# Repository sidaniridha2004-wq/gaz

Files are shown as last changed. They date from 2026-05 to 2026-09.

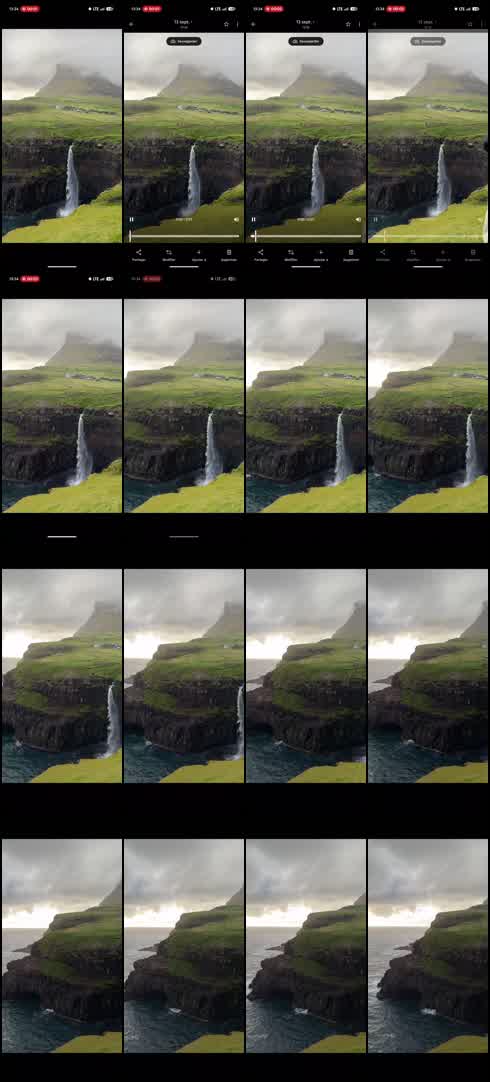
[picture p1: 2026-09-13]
video-analysis/contact-sheet.jpg

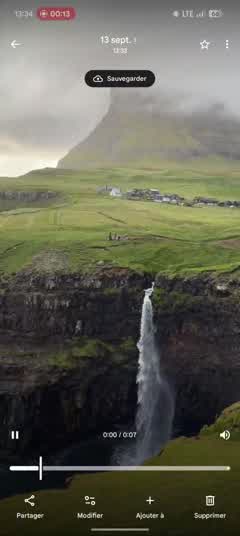
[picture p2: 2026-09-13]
video-analysis/frames/frame-5.jpg

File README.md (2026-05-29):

# Intelligent Home Gas & CO Detection Safety System

An ESP32-based safety system that detects carbon monoxide (CO) and combustible
gas (LPG / methane / propane) in every room of a house and **automatically shuts
off the gas supply at the source** when a confirmed leak is detected.

The system is split into two firmware subsystems that talk over **ESP-NOW**
(router-free, peer-to-peer Wi-Fi):

```
   ┌────────────────────┐        ESP-NOW (encrypted, <5 ms)        ┌───────────────────────────┐
   │  Sensor Node (xN)   │  ───────────────────────────────────▶   │   Central Control Unit     │
   │  per room           │     ALERT / STATUS / CLEAR packets       │   (Hub @ gas source)       │
   │                     │                                          │                            │
   │  ESP32              │                                          │  ESP32                     │
   │  MQ-7  (CO)         │                                          │  Relay ─ Servo ─ Ball valve│
   │  MQ-2  (LPG)        │                                          │  Buzzer                    │
   │  LiPo + TP4056      │                                          │  16x2 I2C LCD              │
   │                     │                                          │  SIM800L GSM (SMS)         │
   └────────────────────┘                                          │  Reset button (interlock)  │
                                                                    └───────────────────────────┘
```

## Repository layout

```
gas-safety-system/
├── platformio.ini              # two build envs: sensor_node + hub
├── lib/common/protocol.h       # shared ESP-NOW packet + thresholds + timing
├── src/
│   ├── sensor_node/
│   │   ├── main.cpp            # sampling, warm-up cal, vote, ESP-NOW TX
│   │   └── mq_sensor.{h,cpp}   # Rs/R0 -> ppm gas-sensor driver
│   └── hub/
│       ├── main.cpp            # ESP-NOW RX, valve, LCD, buzzer, GSM, FSM
│       └── node_registry.h     # MAC <-> room table (edit for your install)
└── docs/
    ├── BOM.md                  # bill of materials + cost
    ├── wiring.md               # pin-by-pin connections
    ├── calibration.md          # MQ sensor calibration procedure
    ├── actuator_3d_print.md    # 3D-printed valve clamp / coupler
    └── test_plan.md            # validation experiments
```

## How it works

### Sensor node (one per room)
1. **Warm-up (120 s):** the MQ heaters stabilise. During this window the node
   averages the clean-air sensor resistance to compute `R0`.
2. **Sampling (every 500 ms):** each sensor's voltage is read on an ADC1 pin,
   converted to a resistance `Rs`, and turned into ppm with the datasheet curve
   `ppm = A·(Rs/R0)^B`.
3. **Majority vote (2 of 3):** a reading only counts as a trip if at least 2 of
   the last 3 samples are over threshold — this rejects single-sample spikes.
4. **Alert:** on a confirmed trip (`CO ≥ 200 ppm` or `LPG ≥ 1000 ppm`) the node
   sends an encrypted `ALERT` packet to the hub (rate-limited to 1 per 10 s).
   It also sends a `STATUS` heartbeat every 5 s and a `CLEAR` packet once the
   air drops back below the lower hysteresis levels.

### Central hub (at the gas source)
On receiving an `ALERT` it executes the **fast safety path in under 1 second**:
close the valve → sound the buzzer → update the LCD. It then sends an SMS to the
homeowner (slower, done after the valve is already shut).

The valve is held **CLOSED** until **both** conditions are met (safety interlock):
* every room reports gas back to safe levels, **and**
* the physical **reset button** on the hub is pressed.

```
 NORMAL ──(alert)──▶ ALARM ──(all rooms clear)──▶ AWAIT_RESET ──(reset btn)──▶ NORMAL
   ▲                                                   │
   └──────────────── (gas returns) ◀───────────────────┘
```

## Build & flash (PlatformIO)

Each room is its own build environment (`node_living_room`, `node_kitchen`,
`node_bedroom`, …). Add a room by copying a `node_*` block in `platformio.ini`
and changing `ROOM_ID` / `ROOM_NAME`. Verified: all environments compile for
`esp32dev`.

```bash
# Install PlatformIO Core (once)
pip install platformio

# Build everything (sanity check)
pio run

# --- Hub ---
pio run -e hub -t upload
pio device monitor -b 115200          # note the printed HUB STA MAC

# --- Sensor nodes (one env per room) ---
pio run -e node_living_room -t upload
pio run -e node_kitchen     -t upload
pio run -e node_bedroom     -t upload
```

### One-time pairing procedure
1. Flash the **hub**, open the serial monitor, copy the printed
   `HUB STA MAC` into `HUB_MAC_BYTES` in `lib/common/protocol.h`.
2. Flash each **node**; copy each printed `Node STA MAC` + its room into
   `src/hub/node_registry.h` (the `roomId` there must match the env's `ROOM_ID`).
3. Re-flash the hub. Nodes and hub now trust each other (encrypted ESP-NOW).
4. Set the homeowner phone number in the `hub` env build flags, e.g.
   `-DHOMEOWNER_PHONE='"+15551234567"'`. Use `-DGSM_ENABLE=0` to build/test
   without a SIM800L attached.

## Key configuration (in `lib/common/protocol.h`)

| Setting | Default | Meaning |
|---|---|---|
| `CO_THRESHOLD_PPM` | 200 | CO alert trip point |
| `LPG_THRESHOLD_PPM` | 1000 | combustible-gas alert trip point |
| `SAMPLE_PERIOD_MS` | 500 | ADC sampling cadence |
| `WARMUP_SEC` | 120 | sensor warm-up / R0 calibration |
| `VOTE_NEEDED / VOTE_WINDOW` | 2 / 3 | majority vote |
| `MIN_ALERT_GAP_MS` | 10000 | min interval between alerts per node |
| `VALVE_OPEN_DEG / CLOSED_DEG` | 0 / 90 | servo angles |

Build-flag options: `ESPNOW_ENCRYPT` (1/0), `GSM_ENABLE` (1/0),
`BOOT_VALVE_OPEN` (1/0), `HOMEOWNER_PHONE`, `ROOM_ID`, `ROOM_NAME`.

## Important engineering notes & limitations

* **ADC1 only on nodes.** ESP-NOW uses the Wi-Fi radio, which makes ADC2 pins
  unusable. The sensors are therefore on GPIO34/35 (ADC1).
* **MQ-7 CO accuracy.** A laboratory-grade MQ-7 reading needs a dual-voltage
  heater cycle (5 V/1.4 V). This prototype runs the common constant-5 V module,
  which is adequate for threshold alarming but not metrology — see
  `docs/calibration.md`.
* **Encrypted-peer limit.** The ESP32 supports at most **6 encrypted** ESP-NOW
  peers. For more than 6 rooms either build with `-DESPNOW_ENCRYPT=0` or run
  multiple hub radios. (The "unlimited nodes" goal holds for the *unencrypted*
  configuration.)
* **Curve constants must be calibrated.** The `A`, `B` and clean-air ratios in
  `src/sensor_node/main.cpp` are datasheet starting points; calibrate against a
  reference per `docs/calibration.md` before trusting absolute ppm values.
* **Safety scope.** This is an academic prototype demonstrating the full
  electromechanical + firmware integration. It is **not** a certified life-safety
  appliance and should not be relied upon as a sole protection device.

See `docs/` for the bill of materials, wiring, calibration, 3D-printed actuator,
and the validation test plan.

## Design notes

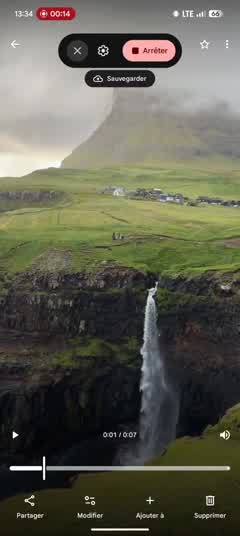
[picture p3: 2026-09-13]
video-analysis/frames/frame-6.jpg

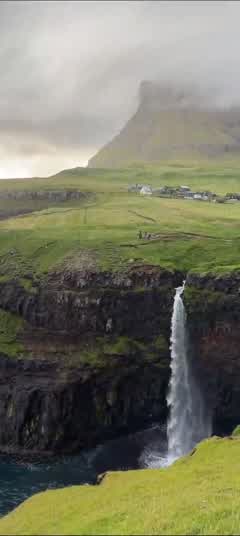
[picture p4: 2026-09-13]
video-analysis/frames/frame-4.jpg

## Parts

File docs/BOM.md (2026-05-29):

# Bill of Materials (BOM)

Indicative hobbyist prices (USD). A **3-room** system = 3 sensor nodes + 1 hub.

## Per sensor node (×N rooms)

| # | Component | Qty | ~Unit | Notes |
|---|---|----:|---:|---|
| 1 | ESP32 DevKit (WROOM-32) | 1 | $4.50 | dual-core, Wi-Fi/ESP-NOW |
| 2 | MQ-7 module (CO) | 1 | $2.00 | analog output |
| 3 | MQ-2 module (LPG/methane) | 1 | $1.80 | analog output |
| 4 | 3.7 V LiPo cell (1200–2000 mAh) | 1 | $4.00 | runtime depends on heaters |
| 5 | TP4056 charge module (w/ protection) | 1 | $0.60 | USB-C charging |
| 6 | MT3608 / 5 V boost converter | 1 | $0.70 | MQ heaters need 5 V |
| 7 | Resistors (divider 10k/20k ×2, batt 2×100k) | — | $0.20 | ADC scaling |
| 8 | Enclosure + vents + wiring | 1 | $2.00 | ventilated for airflow |
| | **Node subtotal** | | **≈ $15.6** | |

> The MQ heaters draw ~150 mA at 5 V continuously, so a node is effectively a
> low-power *plugged* device; the LiPo is primarily for outage ride-through.
> For a permanently battery-only node, budget a larger cell or USB power.

## Central hub (×1)

| # | Component | Qty | ~Unit | Notes |
|---|---|----:|---:|---|
| 1 | ESP32 DevKit (WROOM-32) | 1 | $4.50 | hub controller |
| 2 | MG996R servo (metal gear) | 1 | $3.50 | valve actuator |
| 3 | 1-channel 5 V relay module | 1 | $1.00 | gates servo power |
| 4 | 16×2 I2C LCD (PCF8574) | 1 | $2.50 | status display |
| 5 | SIM800L GSM module + antenna | 1 | $4.50 | SMS alerts |
| 6 | Active buzzer (5 V) | 1 | $0.40 | local alarm |
| 7 | Momentary push button | 1 | $0.20 | manual reset |
| 8 | ¼" brass ball valve | 1 | $3.50 | shutoff element |
| 9 | 3D-printed clamp + coupler (PLA) | 1 | $1.50 | ~40 g filament |
| 10| 5 V 2 A supply + small UPS/power bank | 1 | $6.00 | SIM800L bursts to ~2 A |
| 11| Buck/LDO for SIM800L (~4.0 V) | 1 | $0.80 | SIM800L is not 5 V tolerant |
| | **Hub subtotal** | | **≈ $32.9** | |

## System totals

| System | Nodes | Approx. total |
|---|---:|---:|
| 1-room | 1 | ≈ $48 |
| 3-room | 3 | ≈ $79 |

> The headline "$40–60 for 3 rooms" is achievable with bulk/AliExpress pricing
> and by omitting the UPS/boost extras; the table above is a conservative
> single-unit estimate.

## Critical sourcing notes
* **SIM800L power:** needs a stable 3.4–4.4 V rail able to source ~2 A pulses.
  Powering it from the ESP32 3V3 pin **will not work** and causes brownout
  resets. Use a dedicated buck converter + a large electrolytic cap (≥1000 µF).
* **MG996R stall current** is ~2.5 A. Power the servo from the 5 V rail through
  the relay, **not** from the ESP32 regulator.
* Use a 2G/GSM-capable SIM and confirm 2G is still available in your region.

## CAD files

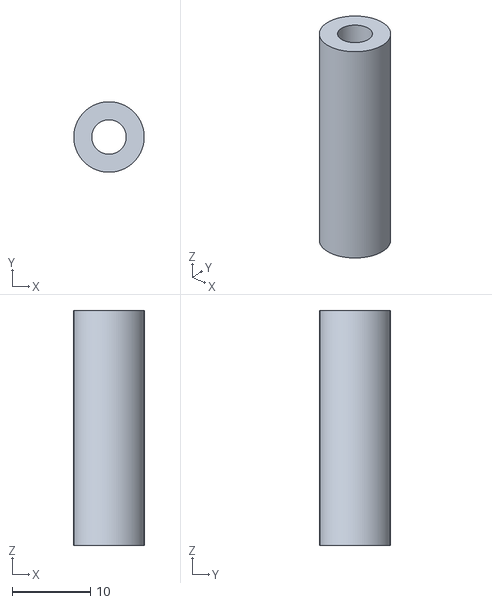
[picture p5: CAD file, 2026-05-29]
cad/stl/standoff.stl
9.00 x 9.00 x 30.0

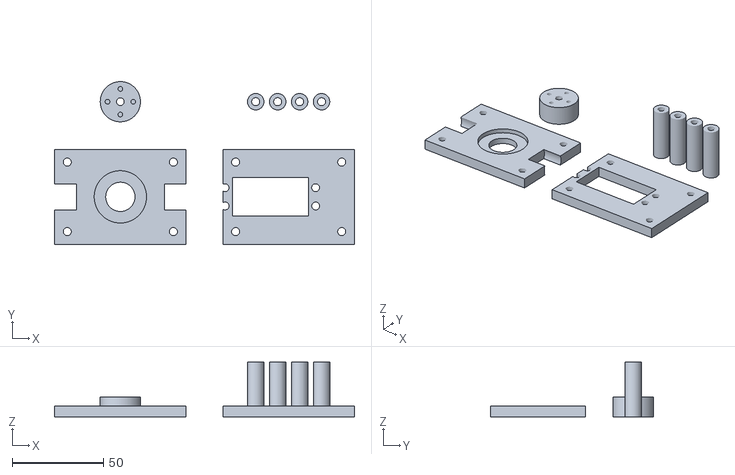
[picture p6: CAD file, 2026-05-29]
cad/stl/print_plate.stl
164.0 x 89.0 x 30.0

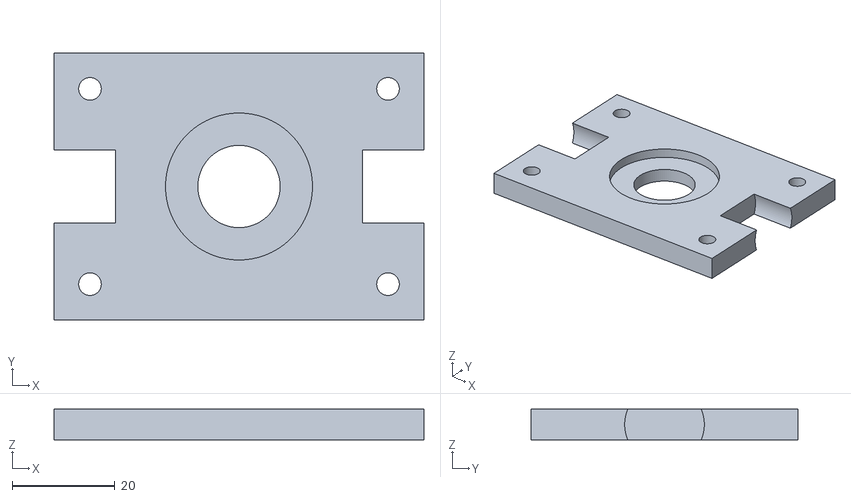
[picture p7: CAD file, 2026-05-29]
cad/stl/bottom_plate.stl
72.0 x 52.0 x 6.00

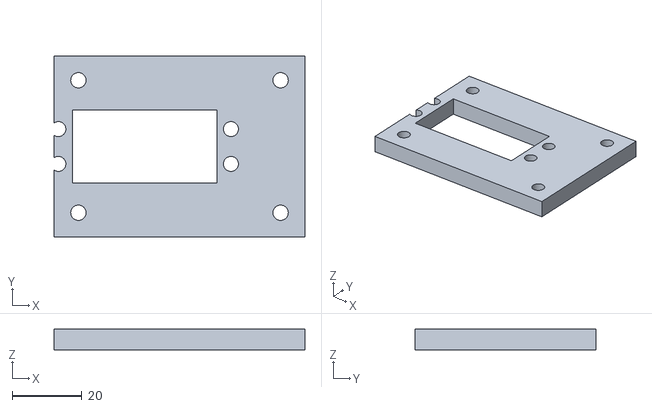
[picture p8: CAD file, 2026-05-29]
cad/stl/top_plate.stl
72.0 x 52.0 x 6.00

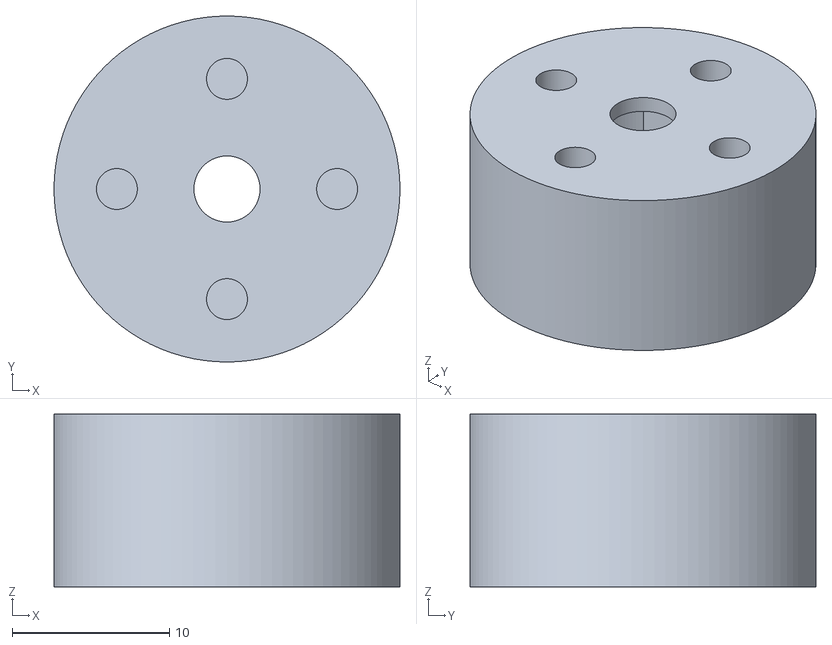
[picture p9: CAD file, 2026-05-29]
cad/stl/stem_coupler.stl
22.0 x 22.0 x 11.0

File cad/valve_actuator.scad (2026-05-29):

// =============================================================================
//  valve_actuator.scad
//  Parametric 3D-printed SERVO-ACTUATED BALL VALVE mount (two-plate cage)
// -----------------------------------------------------------------------------
//  Style: matches the classic servo-actuated ball valve build -> two parallel
//  plates sandwich the valve, joined by FOUR corner standoffs (the yellow rods
//  in the reference photo). The MG996R servo bolts to the TOP plate with its
//  output shaft COAXIAL to the valve stem and drives the stem directly through
//  a coupler. The cage reacts all the torque so nothing twists on the pipe.
//
//      [ TOP PLATE ] <- servo bolts here, shaft on stem axis
//        |  |  |  |    <- 4 standoffs (threaded rod + nuts, or printed)
//      [ BOT PLATE ] <- valve body seats here
//           ||         <- pipe passes out the sides
//
//  Force path: servo horn -> stem_coupler -> valve stem -> ball turns 90 deg.
//
//  PRINTED PARTS:
//    1. bottom_plate   (x1)   seats the valve body, anchors the standoffs
//    2. top_plate      (x1)   holds the servo + clears the stem coupler
//    3. stem_coupler   (x1)   servo horn  ->  valve stem flats
//    4. standoff       (x4)   OPTIONAL printed spacer; or use M4 threaded rod
//
//  Units = mm. Print PETG (preferred) / PLA, 0.2 mm layers, 4 walls,
//  40-60% infill. The coupler is the load-critical part -> print it solid.
// =============================================================================

// ============================ PARAMETERS =====================================
// ---- VALVE (MEASURE YOURS with calipers and edit) --------------------------
valve_body_od     = 28.0;  // round body outer diameter (where it sits in plate)
valve_body_h      = 30.0;  // body height = gap set between the two plates
pipe_od           = 14.0;  // pipe / union OD that exits the sides of the cage
stem_dia          = 7.0;   // round diameter of the valve stem
stem_flat_across  = 5.5;   // distance across the two stem flats (double-D)
stem_flat_len     = 9.0;   // length of the flats down from the stem top
stem_top_z        = 22.0;  // valve body top -> stem top (stem sticks up this far)

// ---- MG996R SERVO (standard; change only for another servo) ----------------
servo_body_l      = 40.5;  // body length
servo_body_w      = 20.0;  // body width
servo_shaft_off   = 10.0;  // output-shaft offset from body length-center
servo_horn_dia    = 24.0;  // round horn outer diameter
servo_horn_th     = 5.0;   // horn thickness (sits in coupler recess)
servo_mh_dia      = 4.3;   // flange mount-hole dia (M4)
servo_mh_span_l   = 49.5;  // flange hole spacing along length
servo_mh_span_w   = 10.0;  // flange hole spacing across width
servo_clear_w     = 21.0;  // body slot width in the plate (body + clearance)
servo_clear_l     = 41.5;  // body slot length in the plate

// ---- PLATES + CAGE ---------------------------------------------------------
plate_l           = 72.0;  // plate length (X)
plate_w           = 52.0;  // plate width  (Y)
plate_th          = 6.0;   // plate thickness
corner_inset      = 7.0;   // standoff hole inset from plate corners
standoff_hole     = 4.4;   // M4 clearance for the standoff rods
standoff_od       = 9.0;   // printed-standoff outer diameter (if used)

// ---- STEM COUPLER ----------------------------------------------------------
coupler_dia       = 22.0;  // coupler outer diameter
coupler_h         = 16.0;  // coupler height
coupler_fit       = 0.30;  // clearance on the stem flats (print tolerance)
horn_screw_dia    = 2.6;   // self-tap holes for horn screws (M2.5/M3)
horn_screw_pcd    = 14.0;  // horn screw pitch-circle diameter
horn_screw_n      = 4;     // number of horn screws

// ---- misc ------------------------------------------------------------------
eps = 0.01;
$fn = 96;

// ============================ DERIVED ========================================
// Standoff hole centers (shared by both plates so the cage lines up).
sx = plate_l/2 - corner_inset;
sy = plate_w/2 - corner_inset;
standoff_pts = [[ sx, sy], [-sx, sy], [-sx,-sy], [ sx,-sy]];

// Servo body center is offset so the output SHAFT lands on the plate center
// (= the valve stem axis). MG996R shaft is servo_shaft_off from body center.
servo_cx = -servo_shaft_off;

// ============================ HELPERS ========================================
// Vertical prism shaped like the valve stem: a cylinder with two flats.
module stem_profile(d, across, h) {
    intersection() {
        cylinder(h = h, d = d);
        cube([d + 1, across, 2*h], center = true);
    }
}

module corner_holes(d) {
    for (p = standoff_pts)
        translate([p[0], p[1], -eps])
            cylinder(h = plate_th + 2*eps, d = d);
}

// ===================== PART 1: BOTTOM PLATE =================================
// The valve body seats in a shallow circular pocket; the pipe escapes through
// side slots. Four corner holes anchor the standoffs.
module bottom_plate() {
    color("Silver")
    difference() {
        // plate
        translate([-plate_l/2, -plate_w/2, 0])
            cube([plate_l, plate_w, plate_th]);

        // shallow seat pocket so the valve body cannot slide around
        translate([0, 0, plate_th - 2.5])
            cylinder(h = 2.5 + eps, d = valve_body_od + 0.6);

        // central bore (lets the lower stem / body boss clear if needed)
        translate([0,0,-eps])
            cylinder(h = plate_th + 2*eps, d = pipe_od + 2);

        // pipe pass-through slots on +X / -X edges
        for (mx = [1, -1])
            translate([mx*plate_l/2, 0, plate_th/2])
                rotate([0,90,0])
                    cylinder(h = 24, d = pipe_od + 1.5, center = true);

        corner_holes(standoff_hole);
    }
}

// ===================== PART 2: TOP PLATE ====================================
// Holds the servo (shaft centered on the stem axis) and clears the coupler.
module top_plate() {
    color("Gainsboro")
    difference() {
        translate([-plate_l/2, -plate_w/2, 0])
            cube([plate_l, plate_w, plate_th]);

        // servo body slot (body drops through; flanges rest on the plate top)
        translate([servo_cx, 0, -eps])
            translate([-servo_clear_l/2, -servo_clear_w/2, 0])
                cube([servo_clear_l, servo_clear_w, plate_th + 2*eps]);

        // servo flange mounting holes (4, around the body slot)
        for (mx = [1,-1])
            for (my = [1,-1])
                translate([servo_cx + mx*servo_mh_span_l/2,
                           my*servo_mh_span_w/2, -eps])
                    cylinder(h = plate_th + 2*eps, d = servo_mh_dia);

        corner_holes(standoff_hole);
    }
}

// ===================== PART 3: STEM COUPLER =================================
// Bottom: socket matching the valve stem double-D. Top: recess + screw holes
// for the servo horn. Servo turns horn -> turns coupler -> turns stem.
module stem_coupler() {
    color("LimeGreen")
    difference() {
        cylinder(h = coupler_h, d = coupler_dia);

        // stem socket (bottom)
        translate([0,0,-eps])
            stem_profile(stem_dia + coupler_fit,
                         stem_flat_across + coupler_fit,
                         stem_flat_len + 1);

        // servo-horn recess (top)
        translate([0,0,coupler_h - servo_horn_th])
            cylinder(h = servo_horn_th + eps, d = servo_horn_dia + 0.6);

        // central clearance through-hole
        translate([0,0,-eps])
            cylinder(h = coupler_h + 2*eps, d = 4.2);

        // horn fixing screws
        for (i = [0:horn_screw_n-1])
            rotate([0,0, i*360/horn_screw_n])
                translate([horn_screw_pcd/2, 0, coupler_h - servo_horn_th - 6])
                    cylinder(h = 6 + eps, d = horn_screw_dia);
    }
}

// ===================== PART 4: STANDOFF (optional printed) ==================
// Use 4. If you prefer metal M4 threaded rod + nuts (like the yellow rods in
// the photo), skip printing these and set the rod length = valve_body_h.
module standoff() {
    color("Goldenrod")
    difference() {
        cylinder(h = valve_body_h, d = standoff_od);
        translate([0,0,-eps])
            cylinder(h = valve_body_h + 2*eps, d = standoff_hole);
    }
}

// ===================== GHOST REFERENCE (not printed) ========================
module ghost_valve() {
    %union() {
        // body
        translate([0,0,-valve_body_h + plate_th])  // sit on bottom plate top
            cylinder(h = valve_body_h, d = valve_body_od);
        // pipe out both sides
        translate([0,0,-valve_body_h/2 + plate_th])
            rotate([0,90,0])
                cylinder(h = plate_l + 30, d = pipe_od, center = true);
        // stem up
        translate([0,0,plate_th])
            stem_profile(stem_dia, stem_flat_across, stem_top_z);
    }
}
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

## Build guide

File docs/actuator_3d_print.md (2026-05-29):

# 3D-Printed Valve Actuator

A custom PLA assembly couples an MG996R servo to a ¼" brass ball valve so a 90°
servo rotation drives the valve handle from **open** to **closed**.

## Assembly (3 printed parts)

```
        ┌─────────────────┐
        │  servo platform │  ← MG996R bolts here (M3), raised so the horn
        │   (bridges the  │     aligns with the valve handle axis
        │   valve body)   │
        └────────┬────────┘
                 │  M3 standoffs
   ┌─────────────┴─────────────┐
   │  two-piece clamp (halves)  │  ← wraps the valve body; M4 bolts pull the
   │  bolted around valve body  │     halves together (rigid, no rotation)
   └────────────────────────────┘

   servo horn ──[coupler arm]── valve handle
   (the arm has a slot/D-profile that grips the OEM handle)
```

1. **Two-piece clamp** – split cylindrical clamp sized to the valve body OD.
   The two halves bolt together (M4) and react the actuation torque so the
   whole assembly does not spin on the pipe.
2. **Servo platform** – mounts on the clamp via standoffs; locates the MG996R so
   its output shaft is coaxial (or parallel-and-offset) with the valve handle.
3. **Coupler arm** – links the servo horn to the valve handle. One end matches
   the MG996R spline (use the OEM horn captured in a pocket, or a printed
   24-tooth spline); the other end is a slot/D-shape gripping the handle.

## Recommended print settings (PLA / PETG)

| Parameter | Value | Reason |
|---|---|---|
| Material | **PETG** preferred (PLA OK indoors) | PETG tolerates heat/creep better |
| Layer height | 0.2 mm | balance of speed/strength |
| Walls / perimeters | 4 | torque-bearing parts |
| Infill | 40–60 % | clamp & coupler see real load |
| Top/bottom layers | 5 | stiffness |
| Orientation | print coupler so layers are **across** the torque path | avoid splitting along layer lines |

> The coupler arm is the most stressed part — print it so the servo torque
> loads the part *across* the layers, not peeling them apart.

## Torque / mechanical check

* MG996R stall torque ≈ **9–11 kg·cm @ 6 V**.
* A clean ¼" ball valve needs roughly **3–6 kg·cm** to turn; verify your actual
  valve with a small torque wrench / luggage scale + lever arm.
* Add a **mechanical hard stop** at the 90° closed position so the servo is not
  fighting the handle end-stop indefinitely (reduces stall heating).
* If torque is marginal, increase the coupler lever length or step up to a
  higher-torque servo (e.g. DS3218, ~20 kg·cm).

## Design files

This repo ships **firmware + design docs**; the CAD/STL files are produced
separately (Fusion 360 / FreeCAD / OpenSCAD). Suggested deliverables to add
under `cad/`:
* `valve_clamp_half.stl` (print ×2)
* `servo_platform.stl`
* `coupler_arm.stl`
* source `.f3d` / `.FCStd` / `.scad`

Parameterise the clamp bore diameter and the handle slot so the same model fits
different valve sizes.

## Safety note

This printed actuator is a **prototype** to demonstrate the electromechanical
integration. A production system would use a listed motorised/solenoid gas
shutoff valve certified for fuel-gas service.

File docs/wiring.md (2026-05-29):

# Wiring Reference

All GPIO numbers match the firmware. Double-check against your specific ESP32
DevKit silkscreen (pin *positions* vary between boards, GPIO *numbers* do not).

## Sensor node

| Signal | ESP32 GPIO | Connects to | Notes |
|---|---|---|---|
| MQ-7 (CO) analog out | **GPIO34** (ADC1_CH6) | divider → MQ-7 `AO` | input-only pin |
| MQ-2 (LPG) analog out | **GPIO35** (ADC1_CH7) | divider → MQ-2 `AO` | input-only pin |
| Battery sense | **GPIO33** (ADC1_CH5) | LiPo+ via 1:2 divider | 4.2 V → 2.1 V |
| Status LED | **GPIO2** | onboard LED | warm-up blink / solid = alert |
| MQ heaters Vcc | 5 V | boost converter out | ~150 mA each |
| Grounds | GND | common | tie all grounds together |

**Why a divider on the MQ outputs?** The MQ modules output up to ~5 V but the
ESP32 ADC tops out at ~3.3 V. Use R1 = 10 kΩ (from `AO`) and R2 = 20 kΩ (to GND);
the ADC reads `AO × 20/30 = 0.667·AO`, i.e. 5 V → 3.33 V. This matches the
firmware's `dividerRatio = 1.5`.

```
 MQ AO ──[10k]──┬── GPIO34/35 (ADC)
                │
              [20k]
                │
               GND
```

Battery divider: two equal resistors (e.g. 100 kΩ/100 kΩ) → `BATT_DIVIDER = 2.0`.

### Power chain (node)
```
LiPo 3.7V ─ TP4056 (charge/protect) ─┬─ MT3608 boost → 5V → MQ heaters
                                     └─ ESP32 5V/VIN (or 3V3 via LDO)
```

## Central hub

| Signal | ESP32 GPIO | Connects to | Notes |
|---|---|---|---|
| Servo PWM | **GPIO13** | MG996R signal | 50 Hz, 500–2400 µs |
| Relay control | **GPIO27** | relay `IN` | active-LOW board (see firmware) |
| Buzzer | **GPIO14** | active buzzer + | HIGH = on |
| Reset button | **GPIO15** | button → GND | uses internal pull-up |
| LCD SDA | **GPIO21** | LCD `SDA` | I2C |
| LCD SCL | **GPIO22** | LCD `SCL` | I2C, addr 0x27 |
| SIM800L → ESP RX | **GPIO16** | SIM800L `TXD` | |
| ESP TX → SIM800L | **GPIO17** | SIM800L `RXD` | level-OK at 3.3 V logic |

### Relay → servo power path
```
5V 2A ──▶ relay COM
relay NO ──▶ MG996R Vcc        (servo powered only when relay is energised)
GPIO27 ──▶ relay IN            (active-LOW: LOW = energise = servo on)
GPIO13 ──▶ MG996R signal
GND common (ESP32 + servo + relay)
```

### SIM800L power (do this right or it browns out)
```
5V ──▶ buck converter ──▶ 4.0 V ──▶ SIM800L VCC
                                     ╫── 1000 µF cap across VCC/GND
GND common with ESP32
```

## Common-ground rule
Every subsystem (ESP32, sensors, servo, relay, SIM800L, LCD) **must share a
common ground**. Floating grounds are the #1 cause of "works on the bench,
fails when assembled" behaviour with these modules.

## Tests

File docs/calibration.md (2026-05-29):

# MQ Sensor Calibration

The firmware reports ppm via the standard MQ model:

```
Rs  = RL · (Vc − Vout) / Vout          # sensor resistance
R0  = Rs_clean_air / clean_air_ratio   # baseline (measured at warm-up)
ppm = A · (Rs / R0)^B                  # datasheet log-log curve
```

There are **two** things to calibrate: the per-unit baseline `R0` (done
automatically) and the gas curve constants `A`, `B` (done once per sensor type).

## 1. Automatic R0 baseline (every boot)

During the 120 s warm-up the node must be in **clean air**. It averages `Rs`
and computes `R0 = Rs_clean / clean_air_ratio` using:

| Sensor | `clean_air_ratio` (Rs/R0 in air) | source |
|---|---|---|
| MQ-2 (LPG) | 9.83 | datasheet |
| MQ-7 (CO)  | 27.0 (verify per unit) | datasheet/empirical |

Watch the serial log line after warm-up:
```
[WARMUP] complete. R0(CO)=NNN ohm  R0(LPG)=NNN ohm
```
A sane MQ-2 `R0` is typically tens of kΩ. Wildly different values usually mean
a wrong `RL`, a missing divider, or a sensor still off-gassing (run it for a few
hours first, "burn-in").

## 2. Gas curve constants A, B

`A` and `B` come from linearising the datasheet curve on a log-log plot:
```
log(ppm) = log(A) + B · log(Rs/R0)   ⇒   pick two points (x1,y1),(x2,y2)
B = (log y1 − log y2) / (log x1 − log x2)
A = y1 / x1^B
```
Read two `(Rs/R0, ppm)` points off the target-gas line in the datasheet
(e.g. MQ-2 LPG curve, MQ-7 CO curve) and compute `A`, `B`. Defaults shipped in
`src/sensor_node/main.cpp`:

| Sensor / gas | A | B |
|---|---|---|
| MQ-7 / CO  | 99.042 | −1.518 |
| MQ-2 / LPG | 574.25 | −2.222 |

Update the `MQSensor` constructor arguments after computing your own.

## 3. Setting RL (load resistor)

Cheap modules have RL set by an onboard resistor or trimmer pot (often
0.5–20 kΩ). Measure it with a multimeter (power off) and set `rlOhms` in the
`MQSensor` constructor to match. The firmware defaults: MQ-7 = 10 kΩ,
MQ-2 = 5 kΩ.

## 4. Reference-gas verification (recommended)

1. Place the node + a calibrated reference detector in a sealed test chamber.
2. Inject a known gas concentration (e.g. a 50 % LEL test-gas can for LPG, or a
   CO test-gas can for MQ-7).
3. Compare the firmware's ppm log against the reference; adjust `A`/`B` until
   the trip points (`200 ppm` CO, `1000 ppm` LPG) line up.
4. Record the response time from injection to `ALERT` for the test plan.

## 5. Known accuracy caveats

* **MQ-7 ideally needs a heater duty cycle** (5 V for 60 s, then 1.4 V for 90 s)
  for accurate CO measurement. This firmware reads at constant 5 V (typical for
  the cheap modules), which is fine for *threshold alarming* but not precise
  metrology. Implementing the dual-voltage cycle is a good extension: drive the
  heater through a transistor/PWM and sample at the end of the low phase.
* MQ sensors drift with temperature/humidity and age; re-verify periodically.
* Treat reported ppm as **relative/indicative**, with the safety value being the
  reliable *crossing* of a calibrated threshold, not the absolute number.

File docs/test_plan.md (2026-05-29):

# Validation & Test Plan

Maps each project claim to a repeatable experiment with a pass criterion.
Record results in the table at the bottom.

## A. Gas concentration / calibration

| ID | Test | Method | Pass criterion |
|----|---|---|---|
| A1 | R0 baseline stability | Boot node 5× in clean air; log `R0` | `R0` within ±15 % across boots |
| A2 | CO trip point | Inject CO test-gas; compare to reference detector | `ALERT` raised within ±20 % of 200 ppm |
| A3 | LPG trip point | Butane/LPG test-gas near sensor | `ALERT` raised at/above ~1000 ppm |
| A4 | ppm curve fit | 3 known concentrations vs logged ppm | monotonic, within ±25 % after A/B fit |

## B. Response time (target: shutoff <1 s after confirmation)

| ID | Test | Method | Pass criterion |
|----|---|---|---|
| B1 | Node detect→TX | Timestamp from threshold cross to `[TX] ALERT` | < ~1.5 s (≈ 3 samples for the vote) |
| B2 | Hub RX→valve | Scope/log: `[RX]` to `[VALVE] CLOSED` | < 1 s |
| B3 | End-to-end | Gas applied → valve physically shut | < 2.5 s total (incl. vote window) |
| B4 | Servo travel | Time servo 0°→90° under load | < 0.7 s, valve fully closed |

> The 2-of-3 vote intentionally adds ~1 sample of latency to reject spikes; the
> *post-confirmation* shutoff (B2) is the <1 s figure.

## C. Wireless range & reliability (ESP-NOW)

| ID | Test | Method | Pass criterion |
|----|---|---|---|
| C1 | Open-air range | Walk node away from hub; watch delivery cb | reliable to ≥ 30 m LoS |
| C2 | Through-walls | Node in adjacent rooms / floors | reliable within a typical house |
| C3 | Packet loss | Count `send FAILED` over 1000 packets | < 1 % at in-house distances |
| C4 | Encryption | Confirm peers paired; sniff to verify payload not plaintext | non-registered device ignored |

## D. False-alarm rejection

| ID | Test | Method | Pass criterion |
|----|---|---|---|
| D1 | Single-sample spike | Inject a 1-sample transient (brief breath/lighter puff <1 s) | **no** `ALERT` (vote rejects it) |
| D2 | Warm-up suppression | Power on next to a gas source | no alert during the 120 s warm-up |
| D3 | Alert rate limit | Sustained over-threshold | ≤ 1 `ALERT` per 10 s per node |
| D4 | Hysteresis chatter | Hold gas just around threshold | no rapid alert/clear oscillation |

## E. Safety interlock & system behaviour

| ID | Test | Method | Pass criterion |
|----|---|---|---|
| E1 | Manual-reset interlock | After alarm, clear air, press reset | valve opens **only** after reset *and* air clear |
| E2 | Premature reset blocked | Press reset while gas still present | valve stays closed |
| E3 | Multi-room | Trigger 2 rooms; clear 1 | valve stays closed until **all** clear |
| E4 | LCD content | Observe display in each state | shows room, gas type, ppm correctly |
| E5 | SMS delivery | Trigger alert | SMS received with room + gas + ppm |
| E6 | Node offline | Power off a node | hub flags it OFFLINE on LCD within 20 s |

## F. Power / resilience

| ID | Test | Method | Pass criterion |
|----|---|---|---|
| F1 | Mains outage | Cut hub mains (UPS), cut node mains (LiPo) | system keeps detecting + can shut valve |
| F2 | Node battery report | Discharge LiPo; check `batt%` in logs | tracks voltage monotonically |
| F3 | Brownout-free GSM | Send SMS while logging hub | no resets during SIM800L TX burst |

## Results log (fill in)

| ID | Date | Result | Measured value | Notes |
|----|---|---|---|---|
| A1 |  |  |  |  |
| B2 |  |  |  |  |
| C1 |  |  |  |  |
| D1 |  |  |  |  |
| E1 |  |  |  |  |
| E3 |  |  |  |  |

## Bench testing without gas
* Use `-DGSM_ENABLE=0` to test the hub without a SIM800L attached.
* Temporarily lower `CO_THRESHOLD_PPM` / `LPG_THRESHOLD_PPM`, or breathe on / use
  a lighter (unlit, brief) near the MQ-2 to push readings up safely.
* The serial logs on both node and hub print every sample, packet and state
  transition, which is sufficient to validate the full logic chain on the bench.

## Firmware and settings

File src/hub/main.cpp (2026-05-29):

// =============================================================================
//  Central Control Unit (Hub) firmware  --  installed at the gas source
// -----------------------------------------------------------------------------
//  Responsibilities:
//    * Listen for encrypted ESP-NOW packets from every registered sensor node.
//    * On a confirmed ALERT, within <1 s:  close the ball valve (relay+servo),
//      sound the buzzer, show the alert on the 16x2 LCD, and SMS the homeowner.
//    * Keep the valve CLOSED until (a) every room reports safe AND (b) the
//      physical reset button is pressed  (safety interlock).
//    * Track per-room liveness, readings and battery for the LCD.
//
//  State machine:   NORMAL  --alert-->  ALARM  --all clear-->  AWAIT_RESET
//                      ^                                            |
//                      +-------------- reset btn + air safe --------+
// =============================================================================
#include <Arduino.h>
#include <WiFi.h>
#include <esp_now.h>
#include <esp_wifi.h>
#include <Wire.h>
#include <LiquidCrystal_I2C.h>
#include <ESP32Servo.h>

#include "protocol.h"
#include "node_registry.h"

// ---- Link encryption (must match the nodes) --------------------------------
#ifndef ESPNOW_ENCRYPT
#define ESPNOW_ENCRYPT 1
#endif

// ---- Homeowner phone number for SMS alerts (E.164) -------------------------
#ifndef HOMEOWNER_PHONE
#define HOMEOWNER_PHONE "+10000000000"
#endif
// Set to 0 to compile/test without a SIM800L attached.
#ifndef GSM_ENABLE
#define GSM_ENABLE 1
#endif

// ---- Pin map ----------------------------------------------------------------
static const uint8_t PIN_SERVO  = 13;  // MG996R signal (PWM)
static const uint8_t PIN_RELAY  = 27;  // gates servo power
static const uint8_t PIN_BUZZER = 14;  // active buzzer (HIGH = on)
static const uint8_t PIN_RESET  = 15;  // momentary reset button to GND
static const uint8_t PIN_SIM_RX = 16;  // ESP RX  <- SIM800L TX
static const uint8_t PIN_SIM_TX = 17;  // ESP TX  -> SIM800L RX
// I2C LCD uses the default SDA=21 / SCL=22.

// Relay board polarity (most blue relay modules are active-LOW).
#define RELAY_ACTIVE_LOW 1
#if RELAY_ACTIVE_LOW
#define RELAY_ON()  digitalWrite(PIN_RELAY, LOW)
#define RELAY_OFF() digitalWrite(PIN_RELAY, HIGH)
#else
#define RELAY_ON()  digitalWrite(PIN_RELAY, HIGH)
#define RELAY_OFF() digitalWrite(PIN_RELAY, LOW)
#endif

// On a clean boot, should gas be flowing? true = open (utility-friendly),
// false = fail-safe closed until all nodes confirm safe + reset is pressed.
#ifndef BOOT_VALVE_OPEN
#define BOOT_VALVE_OPEN 1
#endif

// ---- Peripherals ------------------------------------------------------------
LiquidCrystal_I2C lcd(0x27, 16, 2);
Servo valveServo;

// ---- Hub state machine ------------------------------------------------------
enum HubState { STATE_NORMAL, STATE_ALARM, STATE_AWAIT_RESET };
static HubState state = STATE_NORMAL;
static bool valveClosed = false;

// ---- Per-room runtime state (parallel to NODE_REGISTRY) --------------------
struct RoomState {
  bool     seen      = false;
  uint32_t lastSeenMs = 0;
  uint16_t coPpm     = 0;
  uint16_t lpgPpm    = 0;
  uint8_t  triggered = TRIG_NONE;
  uint8_t  battery   = 0;
  bool     alerting  = false;
  bool     online    = false;
  bool     smsSent   = false;  // SMS already sent for the current event
};
static RoomState rooms[NODE_REGISTRY_COUNT];

// ---- ESP-NOW receive queue (callback -> main loop) -------------------------
struct RxItem {
  int       regIdx;
  SensorMsg msg;
};
static QueueHandle_t rxQueue = nullptr;

// =============================================================================
//  GSM / SIM800L helpers
// =============================================================================
static bool simWaitFor(const char *token, uint32_t timeoutMs) {
  uint32_t start = millis();
  size_t matched = 0;
  size_t need = strlen(token);
  while (millis() - start < timeoutMs) {
    while (Serial2.available()) {
      char c = (char)Serial2.read();
      Serial.write(c);  // mirror modem output to the debug console
      matched = (c == token[matched]) ? matched + 1 : (c == token[0] ? 1 : 0);
      if (matched == need) return true;
    }
    delay(2);
  }
  return false;
}

static void simInit() {
#if GSM_ENABLE
  Serial2.begin(9600, SERIAL_8N1, PIN_SIM_RX, PIN_SIM_TX);
  delay(1500);
  Serial.print(F("[GSM] init "));
  Serial2.print(F("AT\r"));
  bool ok = simWaitFor("OK", 2000);
  Serial2.print(F("AT+CMGF=1\r"));            // SMS text mode
  simWaitFor("OK", 2000);
  Serial2.print(F("AT+CSCS=\"GSM\"\r"));      // GSM character set
  simWaitFor("OK", 2000);
  Serial.println(ok ? F("OK") : F("(no response - check power/antenna)"));
#else
  Serial.println(F("[GSM] disabled at build time"));
#endif
}

static void sendSMS(const char *text) {
#if GSM_ENABLE
  Serial.printf("[GSM] SMS -> %s : %s\n", HOMEOWNER_PHONE, text);
  Serial2.print(F("AT+CMGF=1\r"));
  simWaitFor("OK", 2000);
  Serial2.print(F("AT+CMGS=\""));
  Serial2.print(F(HOMEOWNER_PHONE));
  Serial2.print(F("\"\r"));
  delay(300);                 // wait for the '>' prompt
  Serial2.print(text);
  Serial2.write(26);          // Ctrl+Z ends the message
  bool ok = simWaitFor("OK", 8000);
  Serial.println(ok ? F("[GSM] SMS sent") : F("[GSM] SMS send timeout"));
#else
  Serial.printf("[GSM-SIM] would SMS: %s\n", text);
#endif
}

// =============================================================================
//  Valve actuator (relay-gated servo)
// =============================================================================
static void closeValve() {
  RELAY_ON();                          // power the servo
  delay(20);
  valveServo.write(VALVE_CLOSED_DEG);  // rotate handle 90deg -> shut
  valveClosed = true;
  Serial.println(F("[VALVE] CLOSED (gas cut off)"));
  // Servo remains powered to hold torque against the valve spring.
}

static void openValve() {
  RELAY_ON();
  delay(20);
  valveServo.write(VALVE_OPEN_DEG);
  delay(800);                          // allow the handle to travel
  RELAY_OFF();                         // de-power servo to save energy
  valveClosed = false;
  Serial.println(F("[VALVE] OPEN (gas restored)"));
}

// =============================================================================
//  LCD helpers
// =============================================================================
static void lcdLine(uint8_t row, const String &s) {
  String line = s;
  while (line.length() < 16) line += ' ';
  if (line.length() > 16) line = line.substring(0, 16);
  lcd.setCursor(0, row);
  lcd.print(line);
}

// =============================================================================
//  Buzzer (non-blocking patterns)
// =============================================================================
static void updateBuzzer() {
  uint32_t now = millis();
  switch (state) {
    case STATE_ALARM:
      digitalWrite(PIN_BUZZER, (now / 300) % 2);   // fast on/off
      break;
    case STATE_AWAIT_RESET:
      digitalWrite(PIN_BUZZER, (now % 3000) < 80); // short chirp every 3 s
      break;
    default:
      digitalWrite(PIN_BUZZER, LOW);
      break;
  }
}

// =============================================================================
//  ESP-NOW
// =============================================================================
// Arduino-ESP32 2.0.x callback signature (IDF 4.4): sender MAC + payload.
static void onDataRecv(const uint8_t *mac, const uint8_t *data, int len) {
  if (len != (int)sizeof(SensorMsg)) return;
  SensorMsg m;
  memcpy(&m, data, sizeof(m));
  if (m.version != PROTOCOL_VERSION) return;

  int idx = registryIndexForMac(mac);
  if (idx < 0) return;  // packet from an unregistered device -> ignore

  RxItem item;
  item.regIdx = idx;
  item.msg = m;
  if (rxQueue) xQueueSend(rxQueue, &item, 0);
}

static void initEspNow() {
  WiFi.mode(WIFI_STA);
  WiFi.disconnect();
  esp_wifi_set_channel(ESPNOW_CHANNEL, WIFI_SECOND_CHAN_NONE);

  Serial.print(F("[BOOT] HUB STA MAC (put this in HUB_MAC_BYTES on nodes): "));
  Serial.println(WiFi.macAddress());

  if (esp_now_init() != ESP_OK) {
    Serial.println(F("[FATAL] esp_now_init failed -- rebooting"));
    delay(2000);
    ESP.restart();
  }
  esp_now_register_recv_cb(onDataRecv);

#if ESPNOW_ENCRYPT
  esp_now_set_pmk((const uint8_t *)ESPNOW_PMK);
#endif

  // Register every known node so encrypted frames can be decrypted.
  for (size_t i = 0; i < NODE_REGISTRY_COUNT; ++i) {
    esp_now_peer_info_t peer = {};
    memcpy(peer.peer_addr, NODE_REGISTRY[i].mac, 6);
    peer.channel = ESPNOW_CHANNEL;
    peer.ifidx   = WIFI_IF_STA;
#if ESPNOW_ENCRYPT
    peer.encrypt = true;
    memcpy(peer.lmk, ESPNOW_LMK, 16);
#else
    peer.encrypt = false;
#endif
    if (esp_now_add_peer(&peer) != ESP_OK) {
      Serial.printf("[WARN] could not add peer for room %u\n",
                    NODE_REGISTRY[i].roomId);
    }
  }
  Serial.printf("[BOOT] %u node(s) registered, encryption=%d\n",
                (unsigned)NODE_REGISTRY_COUNT, ESPNOW_ENCRYPT);
}

// =============================================================================
//  Reset button (debounced, falling-edge = press)
// =============================================================================
static bool resetPressed() {
  static int lastReading = HIGH;
  static int stable = HIGH;
  static uint32_t lastChange = 0;
  int reading = digitalRead(PIN_RESET);
  if (reading != lastReading) {
    lastReading = reading;
    lastChange = millis();
  }
  if ((millis() - lastChange) > 50 && reading != stable) {
    stable = reading;
    if (stable == LOW) return true;  // press detected
  }
  return false;
}

// =============================================================================
//  Alarm / state-machine helpers
// =============================================================================
static const char *triggeredGasText(uint8_t trig) {
  if ((trig & TRIG_CO) && (trig & TRIG_LPG)) return "CO+LPG";
  if (trig & TRIG_CO)  return "CO";
  if (trig & TRIG_LPG) return "LPG";
  return "GAS";
}

static int firstAlertingRoom() {
  for (size_t i = 0; i < NODE_REGISTRY_COUNT; ++i)
    if (rooms[i].seen && rooms[i].alerting) return (int)i;
  return -1;
}

static bool anyAlerting() { return firstAlertingRoom() >= 0; }

static void enterAlarm() {
  state = STATE_ALARM;
  closeValve();  // fast path: gas off first
  Serial.println(F("[STATE] -> ALARM"));
}

// Compose + send the SMS for a newly alerting room.
static void smsForRoom(int i) {
  char buf[140];
  snprintf(buf, sizeof(buf),
           "GAS ALERT! %s (room %u): %s detected. CO=%u ppm, LPG=%u ppm. "
           "Gas valve CLOSED.",
           NODE_REGISTRY[i].name, NODE_REGISTRY[i].roomId,
           triggeredGasText(rooms[i].triggered), rooms[i].coPpm,
           rooms[i].lpgPpm);
  sendSMS(buf);
}

static void processMessage(const RxItem &item) {
  int i = item.regIdx;
  const SensorMsg &m = item.msg;
  RoomState &r = rooms[i];

  r.seen       = true;
  r.online     = true;
  r.lastSeenMs = millis();
  r.coPpm      = m.coPpm;
  r.lpgPpm     = m.lpgPpm;
  r.triggered  = m.triggered;
  r.battery    = m.batteryPct;

  bool danger = (m.msgType == MSG_ALERT) || (m.triggered != TRIG_NONE);
  bool clear  = (m.msgType == MSG_CLEAR);

  Serial.printf("[RX] room=%u type=%u trig=0x%02X CO=%u LPG=%u batt=%u%% seq=%lu\n",
                m.roomId, m.msgType, m.triggered, m.coPpm, m.lpgPpm,
                m.batteryPct, (unsigned long)m.seq);

  if (danger) {
    if (!r.alerting) {
      r.alerting = true;
      r.smsSent = false;  // new event -> allow one SMS
    }
  } else if (clear) {
    r.alerting = false;
  } else {  // STATUS with no trigger flag
    if (r.alerting && m.coPpm < CO_CLEAR_PPM && m.lpgPpm < LPG_CLEAR_PPM) {
      r.alerting = false;
    }
  }
}

// =============================================================================
//  LCD rendering (rotates through rooms in NORMAL)
// =============================================================================
static void updateLcd() {
  static uint32_t lastDraw = 0;
  static uint8_t rotor = 0;
  if (millis() - lastDraw < 1500) return;
  lastDraw = millis();

  if (state == STATE_ALARM) {
    int i = firstAlertingRoom();
    lcdLine(0, "** GAS ALERT **");
    if (i >= 0) {
      char b[20];
      snprintf(b, sizeof(b), "%s %s", NODE_REGISTRY[i].name,
               triggeredGasText(rooms[i].triggered));
      lcdLine(1, b);
    } else {
      lcdLine(1, "Valve CLOSED");
    }
    return;
  }

  if (state == STATE_AWAIT_RESET) {
    lcdLine(0, "Air CLEAR - safe");
    lcdLine(1, "Press RESET btn");
    return;
  }

  // NORMAL: header + rotating per-room readings.
  lcdLine(0, valveClosed ? "SYSTEM  VALVE-CL" : "SYSTEM OK  GAS:ON");
  if (NODE_REGISTRY_COUNT == 0) {
    lcdLine(1, "No nodes");
    return;
  }
  rotor = (rotor + 1) % NODE_REGISTRY_COUNT;
  RoomState &r = rooms[rotor];
  char b[20];
  if (!r.seen) {
    snprintf(b, sizeof(b), "%s --", NODE_REGISTRY[rotor].name);
  } else if (!r.online) {
    snprintf(b, sizeof(b), "%s OFFLINE", NODE_REGISTRY[rotor].name);
  } else {
    snprintf(b, sizeof(b), "%s C%u L%u", NODE_REGISTRY[rotor].name, r.coPpm,
             r.lpgPpm);
  }
  lcdLine(1, b);
}

// =============================================================================
//  Arduino entry points
// =============================================================================
void setup() {
  Serial.begin(115200);
  delay(200);
  Serial.println(F("\n=== Gas Safety Central Control Unit (Hub) ==="));

  pinMode(PIN_RELAY, OUTPUT);
  RELAY_OFF();
  pinMode(PIN_BUZZER, OUTPUT);
  digitalWrite(PIN_BUZZER, LOW);
  pinMode(PIN_RESET, INPUT_PULLUP);

  // LCD
  Wire.begin();
  lcd.init();
  lcd.backlight();
  lcdLine(0, "Gas Safety Hub");
  lcdLine(1, "starting...");

  // Servo / valve
  ESP32PWM::allocateTimer(0);
  valveServo.setPeriodHertz(50);
  valveServo.attach(PIN_SERVO, 500, 2400);  // MG996R pulse range (us)
#if BOOT_VALVE_OPEN
  openValve();
  state = STATE_NORMAL;
#else
  // Fail-safe: stay closed until air is confirmed clear and reset is pressed.
  closeValve();
  state = STATE_AWAIT_RESET;
#endif

  rxQueue = xQueueCreate(16, sizeof(RxItem));
  initEspNow();
  simInit();

  Serial.println(F("[BOOT] hub ready, monitoring nodes."));
}

void loop() {
  uint32_t now = millis();

  // 1) Drain received packets.
  RxItem item;
  while (rxQueue && xQueueReceive(rxQueue, &item, 0) == pdTRUE) {
    processMessage(item);
  }

  // 2) Mark stale nodes offline.
  for (size_t i = 0; i < NODE_REGISTRY_COUNT; ++i) {
    if (rooms[i].seen && (now - rooms[i].lastSeenMs) > NODE_OFFLINE_MS) {
      rooms[i].online = false;
    }
  }

  // 3) Send SMS for any room that just entered alert.
  for (size_t i = 0; i < NODE_REGISTRY_COUNT; ++i) {
    if (rooms[i].alerting && !rooms[i].smsSent) {
      rooms[i].smsSent = true;
      if (state != STATE_ALARM) enterAlarm();  // ensure valve shut first
      smsForRoom((int)i);
    }
  }

  // 4) State transitions.
  bool danger = anyAlerting();
  switch (state) {
    case STATE_NORMAL:
      if (danger) enterAlarm();
      break;
    case STATE_ALARM:
      if (!danger) {
        state = STATE_AWAIT_RESET;  // valve stays CLOSED (interlock)
        Serial.println(F("[STATE] ALARM -> AWAIT_RESET (air clear)"));
      }
      break;
    case STATE_AWAIT_RESET:
      if (danger) {
        enterAlarm();  // gas came back before reset
      } else if (resetPressed()) {
        openValve();
        for (size_t i = 0; i < NODE_REGISTRY_COUNT; ++i) rooms[i].smsSent = false;
        state = STATE_NORMAL;
        Serial.println(F("[STATE] AWAIT_RESET -> NORMAL (manual reset)"));
      }
      break;
  }

  // 5) Outputs.
  updateBuzzer();
  updateLcd();
}

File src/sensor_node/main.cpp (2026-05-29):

// =============================================================================
//  Sensor Node firmware  --  one per room
// -----------------------------------------------------------------------------
//  Responsibilities:
//    * Sample MQ-7 (CO) and MQ-2 (LPG) every 500 ms via ADC1.
//    * Warm up for 120 s, calibrating R0 in clean air.
//    * Convert readings to ppm and apply a 2-of-3 majority vote.
//    * On a confirmed over-threshold event, transmit an encrypted ESP-NOW
//      ALERT packet to the hub (rate-limited to one per 10 s).
//    * Send a heartbeat STATUS packet every 5 s and a CLEAR packet when the
//      air returns to safe levels (needed for the hub's reopen interlock).
//
//  Build identity is injected per device:  -DROOM_ID=2 -DROOM_NAME='"Kitchen"'
// =============================================================================
#include <Arduino.h>
#include <WiFi.h>
#include <esp_now.h>
#include <esp_wifi.h>

#include "protocol.h"
#include "mq_sensor.h"

// ---- Per-node identity (overridable via build flags) ------------------------
#ifndef ROOM_ID
#define ROOM_ID 1
#endif
#ifndef ROOM_NAME
#define ROOM_NAME "Room"
#endif

// ---- Enable/disable ESP-NOW link encryption --------------------------------
//  Encryption is recommended, but the ESP32 supports at most 6 *encrypted*
//  peers on the hub. For very large installations set -DESPNOW_ENCRYPT=0.
#ifndef ESPNOW_ENCRYPT
#define ESPNOW_ENCRYPT 1
#endif

// ---- Pin map (ADC1 only -- ADC2 is unusable while Wi-Fi/ESP-NOW is on) ------
static const uint8_t PIN_MQ7_CO  = 34;  // ADC1_CH6 (input-only)
static const uint8_t PIN_MQ2_LPG = 35;  // ADC1_CH7 (input-only)
static const uint8_t PIN_BATT    = 33;  // ADC1_CH5 (battery divider)
static const uint8_t PIN_LED     = 2;   // onboard status LED

// ---- Battery (3.7 V LiPo via 1:2 divider) ----------------------------------
static const float BATT_DIVIDER = 2.0f;   // two equal resistors
static const float BATT_FULL_V  = 4.20f;  // 100 %
static const float BATT_EMPTY_V = 3.30f;  // 0 %

// ---- Sensor objects ---------------------------------------------------------
//  Curve coefficients (A,B) and clean-air ratios are datasheet starting points
//  and MUST be refined during calibration (see docs/calibration.md).
//                     pin           RL      Vc    div   cleanRatio   A         B
MQSensor mq7(PIN_MQ7_CO,  10000.0f, 5.0f, 1.5f,  27.00f,    99.042f, -1.518f);
MQSensor mq2(PIN_MQ2_LPG,  5000.0f, 5.0f, 1.5f,   9.83f,   574.250f, -2.222f);

// ---- Hub peer ---------------------------------------------------------------
static uint8_t hubMac[6] = HUB_MAC_BYTES;

// ---- Runtime state ----------------------------------------------------------
static bool     sensorsReady   = false;   // true once warm-up completes
static uint32_t bootMs         = 0;
static uint32_t lastSampleMs   = 0;
static uint32_t lastStatusMs   = 0;
static uint32_t lastAlertMs    = 0;
static uint32_t seqCounter     = 0;
static bool     alertActive    = false;   // currently in an alert condition
static uint8_t  lastTriggered  = TRIG_NONE;

// 2-of-3 majority-vote ring buffers (one bit per recent reading).
static bool coVote[VOTE_WINDOW]  = {false};
static bool lpgVote[VOTE_WINDOW] = {false};
static uint8_t voteIdx   = 0;
static uint8_t voteCount = 0;   // saturates at VOTE_WINDOW

// Latest computed concentrations (cached for packets/logging).
static float coPpm  = 0.0f;
static float lpgPpm = 0.0f;

// -----------------------------------------------------------------------------
//  Helpers
// -----------------------------------------------------------------------------
static uint8_t countTrue(const bool *buf) {
  uint8_t n = 0;
  for (uint8_t i = 0; i < VOTE_WINDOW; ++i) n += buf[i] ? 1 : 0;
  return n;
}

static uint8_t readBatteryPercent() {
  uint32_t mv = 0;
  for (uint8_t i = 0; i < 16; ++i) mv += analogReadMilliVolts(PIN_BATT);
  float vbat = (mv / 16.0f) / 1000.0f * BATT_DIVIDER;
  float pct = (vbat - BATT_EMPTY_V) / (BATT_FULL_V - BATT_EMPTY_V) * 100.0f;
  if (pct < 0.0f) pct = 0.0f;
  if (pct > 100.0f) pct = 100.0f;
  return (uint8_t)(pct + 0.5f);
}

// ESP-NOW transmit-complete callback (diagnostics only).
static void onDataSent(const uint8_t *mac, esp_now_send_status_t status) {
  (void)mac;
  if (status != ESP_NOW_SEND_SUCCESS) {
    Serial.println(F("[ESP-NOW] send FAILED (hub out of range / powered off?)"));
  }
}

static void sendMessage(uint8_t msgType, uint8_t triggered) {
  SensorMsg msg = {};
  msg.version    = PROTOCOL_VERSION;
  msg.msgType    = msgType;
  msg.roomId     = (uint8_t)ROOM_ID;
  msg.triggered  = triggered;
  msg.coPpm      = (uint16_t)(coPpm  + 0.5f);
  msg.lpgPpm     = (uint16_t)(lpgPpm + 0.5f);
  msg.batteryPct = readBatteryPercent();
  msg.reserved   = 0;
  msg.seq        = ++seqCounter;
  msg.uptimeSec  = (millis() - bootMs) / 1000;

  esp_err_t r = esp_now_send(hubMac, (const uint8_t *)&msg, sizeof(msg));
  Serial.printf("[TX] type=%u room=%u trig=0x%02X CO=%uppm LPG=%uppm batt=%u%% seq=%lu %s\n",
                msgType, msg.roomId, triggered, msg.coPpm, msg.lpgPpm,
                msg.batteryPct, (unsigned long)msg.seq,
                (r == ESP_OK) ? "queued" : "ERR");
}

static bool initEspNow() {
  WiFi.mode(WIFI_STA);
  WiFi.disconnect();
  // Pin the radio to the agreed channel so node and hub always match.
  esp_wifi_set_channel(ESPNOW_CHANNEL, WIFI_SECOND_CHAN_NONE);

  Serial.print(F("[BOOT] Node STA MAC: "));
  Serial.println(WiFi.macAddress());

  if (esp_now_init() != ESP_OK) {
    Serial.println(F("[ERR] esp_now_init failed"));
    return false;
  }
  esp_now_register_send_cb(onDataSent);

#if ESPNOW_ENCRYPT
  esp_now_set_pmk((const uint8_t *)ESPNOW_PMK);
#endif

  esp_now_peer_info_t peer = {};
  memcpy(peer.peer_addr, hubMac, 6);
  peer.channel = ESPNOW_CHANNEL;
  peer.ifidx   = WIFI_IF_STA;
#if ESPNOW_ENCRYPT
  peer.encrypt = true;
  memcpy(peer.lmk, ESPNOW_LMK, 16);
#else
  peer.encrypt = false;
#endif
  if (esp_now_add_peer(&peer) != ESP_OK) {
    Serial.println(F("[ERR] esp_now_add_peer (hub) failed"));
    return false;
  }
  Serial.printf("[BOOT] Hub peer registered %02X:%02X:%02X:%02X:%02X:%02X (encrypt=%d)\n",
                hubMac[0], hubMac[1], hubMac[2], hubMac[3], hubMac[4], hubMac[5],
                ESPNOW_ENCRYPT);
  return true;
}
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

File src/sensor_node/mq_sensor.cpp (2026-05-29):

// =============================================================================
//  mq_sensor.cpp  --  Implementation of the MQ gas-sensor driver
// =============================================================================
#include "mq_sensor.h"

// Number of ADC samples averaged per measurement to suppress noise.
static const uint8_t ADC_OVERSAMPLE = 16;

MQSensor::MQSensor(uint8_t adcPin, float rlOhms, float vcVolts,
                   float dividerRatio, float cleanAirRatio, float curveA,
                   float curveB)
    : _pin(adcPin),
      _rl(rlOhms),
      _vc(vcVolts),
      _divider(dividerRatio),
      _cleanRatio(cleanAirRatio),
      _a(curveA),
      _b(curveB) {}

void MQSensor::begin() {
  // 11 dB attenuation -> full-scale ~3.3 V, matching the external divider.
  analogSetPinAttenuation(_pin, ADC_11db);
  pinMode(_pin, INPUT);
}

float MQSensor::readAdcVolts() {
  // analogReadMilliVolts() applies the per-chip eFuse calibration, which is
  // far more accurate than scaling the raw 0-4095 count by hand.
  uint32_t accum_mv = 0;
  for (uint8_t i = 0; i < ADC_OVERSAMPLE; ++i) {
    accum_mv += analogReadMilliVolts(_pin);
  }
  return (accum_mv / (float)ADC_OVERSAMPLE) / 1000.0f;
}

float MQSensor::readVoltage() {
  // Undo the external resistor divider to recover the true sensor output.
  return readAdcVolts() * _divider;
}

float MQSensor::readRs() {
  float vout = readVoltage();
  // Guard against divide-by-zero / disconnected sensor (Vout ~ 0).
  if (vout < 0.01f) {
    return 1.0e9f;  // effectively infinite resistance -> ~0 ppm
  }
  float rs = _rl * (_vc - vout) / vout;
  if (rs < 0.0f) rs = 0.0f;  // can happen on noise when Vout > Vc
  return rs;
}

void MQSensor::resetCalibration() {
  _calSum = 0.0;
  _calCount = 0;
}

void MQSensor::accumulateCalibration() {
  _calSum += readRs();
  _calCount++;
}

void MQSensor::finishCalibration() {
  if (_calCount == 0) return;
  float rsClean = (float)(_calSum / (double)_calCount);
  _r0 = rsClean / _cleanRatio;
  if (_r0 < 1.0f) _r0 = 1.0f;  // sanity floor
}

float MQSensor::readPpm() {
  float ratio = readRs() / _r0;
  if (ratio <= 0.0f) return 0.0f;
  float ppm = _a * powf(ratio, _b);
  if (ppm < 0.0f || isnan(ppm) || isinf(ppm)) ppm = 0.0f;
  return ppm;
}

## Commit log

2026-05-29 Add parametric OpenSCAD valve actuator design (clamp + servo platform + coupler arm)
    [valve_actuator.scad]
2026-05-29 Redesign actuator as servo-actuated ball valve (two-plate cage, direct stem drive) + validated STLs
    [bottom_plate.stl, print_plate.stl, standoff.stl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]
2026-09-13 Remove temporary video analysis frame 0
2026-09-13 Remove temporary video analysis frame 1
2026-09-13 Remove temporary video analysis frame 2
2026-09-13 Remove temporary video analysis frame 3
